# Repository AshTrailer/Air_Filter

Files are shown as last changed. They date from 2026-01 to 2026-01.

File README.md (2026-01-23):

## Air_Filter

Air_Filter is a compact, modular soldering fume extraction and air filtration device designed as a personal hardware project.

The enclosure measures approximately 9.8 × 11 × 11 cm and is constructed as a two-part, chamfered square housing, assembled using M3 fasteners. Inside, it integrates a Sanyo centrifugal blower capable of generating nearly 700 Pa of static pressure at 12 V, providing strong suction performance for soldering smoke removal.

Power is supplied via a standard DC jack, and airflow is adjustable through a rotary PWM control knob. The fan speed is controlled by a potentiometer-driven PWM generator, allowing smooth and flexible airflow regulation.

The mechanical design supports multiple fan orientations. In an upright configuration (front-facing intake), the device allows three different placement orientations. When laid horizontally, the outlet direction can be freely adjusted to suit different workspace layouts.

The filtration module is designed to be detachable and replaceable, enabling easy maintenance and future filter upgrades.

This repository documents the mechanical design, electronics, and overall system concept of the Air_Filter project, intended for learning, experimentation, and open-source sharing.

## Air_Filter
Air_Filter 是一个紧凑型、模块化的焊接烟气过滤与空气抽吸装置，是一个个人硬件设计与实现项目。

整机外壳尺寸约为 9.8 × 11 × 11 cm，采用带倒角的方形结构设计，由上下两部分组成，通过 M3 螺丝与螺母进行装配固定。内部集成了一款山洋（Sanyo）离心风机，在 12 V 供电条件下可提供接近 700 Pa 的静压，具备较强的烟气抽吸能力，适用于焊接烟雾的捕集与过滤。

设备通过标准 DC Jack 接口供电，侧面设有 PWM 调速旋钮。风机转速由电位器控制的 PWM 发生器进行调节，可实现平滑、可控的风量调节。

在结构设计上，该风机支持多种安装与摆放方式。在竖直放置（正面进气）的情况下，可实现三种不同的摆放方向；在水平放置时，出风口方向可根据使用环境自由调整，以适应不同的工作台布局。

过滤模块采用可拆卸、可更换的结构设计，便于维护与后续升级不同类型的过滤介质。

本仓库用于记录 Air_Filter 项目的整体设计思路，包括机械结构、电气控制以及系统集成方案，主要用于学习、实验与开源分享。

## Design Background & Motivation  
## 设计背景与动机

**时间：2026 年 1 月 12 日**

在日常焊接过程中，无论是 DIY 用户还是电子工程相关学习者，都会不可避免地接触到大量焊接烟气。这些烟气中往往包含松香、助焊剂残留以及细小颗粒物，长期吸入对健康存在潜在危害。

在调研过程中发现，市面上常见的焊接烟气过滤装置普遍存在以下问题：

- 体积较大，占用工作台空间  
- 价格偏高，不适合个人或 DIY 用户  
- 结构封闭，难以维护或自行改造  

因此，基于**小型化、可维护、可复用、适合个人工作台**的目标，萌生了自行设计并实现一款紧凑型焊接烟气过滤装置的想法。

在实际设计与制作过程中遇到了大量问题，包括结构强度、风道设计、噪声控制、过滤效率与体积之间的权衡等。这些问题均在实践中逐一分析并尝试解决。目前该项目已经基本完成既定目标。

---
Design Evolution & Versions
设计迭代与版本演进

This project is developed iteratively. Each version focuses on validating different aspects of mechanical design, airflow performance, noise control, and manufacturability.
The following sections document the design rationale, trade-offs, and lessons learned from each version.
Testing

---
Version 1 – Initial Prototype
第一版原型设计（V1）

Development Time: January 12, 2026
Status: Functional prototype


V2_3d_print
V1_total_view
V1_dimension_1
V1_dimension_2

Design Objectives
设计目标

The first version focused on validating the core feasibility of a compact, desktop-sized soldering fume extraction device, with the following priorities:
Compact overall size suitable for personal workbenches
Sufficient suction performance for soldering smoke capture
Modular structure for easy disassembly and maintenance
Rapid prototyping using 3D printing

第一版主要用于验证一款紧凑型桌面焊接烟雾抽取装置的核心可行性，设计优先考虑以下方面：
体积紧凑，适合个人工作台
吸烟能力足够捕集焊接烟雾
模块化结构，便于拆装和维护
通过 3D 打印快速原型制作

---
Overall Architecture
整体结构

The system is divided into two primary modules:
Base Module – fan mounting and structural support
Transmission Roll Module – airflow guidance and filtration
This modular approach simplifies assembly, maintenance, and future design iterations.

系统分为两个主要模块：
Base Module（风机基座） – 用于风机固定和结构支撑
Transmission Roll Module（过滤与风道模块） – 用于气流导向和过滤
这种模块化设计简化了装配、维护以及未来迭代。

---
Base Module Design
Base（风机基座）设计

The Base module is responsible for mounting and supporting the centrifugal blower.
Key design considerations include:
Strict adherence to fan datasheet dimensions and mounting features
Structural strength based on the mechanical properties of 3D printing materials
Support for multiple fan orientations and placement configurations
Special attention was paid to screw load distribution, wall thickness, and vibration caused by fan operation to ensure long-term mechanical reliability.

Base 模块用于固定和支撑离心风机。
主要设计考虑：
严格遵循风机 datasheet 中的安装尺寸和特征
基于 3D 打印材料力学特性确保结构强度
支持多种风机摆放方向和安装方式
特别注意了螺丝受力分布、壁厚设计，以及风机运行时产生的振动，保证长期机械可靠性。

---
Transmission Roll Module
Transmission Roll（过滤与风道模块）

This module handles airflow redirection, filtration, and exhaust.
Design goals:
Compact and portable form factor
Detachable and replaceable filtration module
Reduced internal dead zones and ineffective airflow paths
To minimize overall size, the V1 design abandoned a traditional long, straight duct and instead adopted a short, rapidly changing airflow path.

Trade-off:
This approach increased airflow turbulence, resulting in noticeably higher noise levels during operation.
Mitigation strategy:
Fan speed reduction via PWM control
Accepting reduced peak suction in exchange for improved acoustic comfort

该模块负责气流导向、过滤和排风。
设计目标：
小型便携
可拆卸、更换的过滤模块
减少内部死角和无效风道
为控制整体尺寸，V1 设计舍弃了传统长直风道，采用短而快速变化的风道。

权衡：
这种设计增加了气流湍流，导致运行时噪声明显增加。
解决策略：
通过 PWM 调速降低风机转速
在可接受吸力范围内，以牺牲峰值性能换取更舒适的噪声水平

---
Fan Selection & Filtration Strategy
风机选型与过滤方案

A Sanyo centrifugal blower was selected due to its ability to provide high static pressure (~700 Pa at 12 V), which is critical for overcoming the pressure drop introduced by multi-stage filtration.
The filtration strategy consists of:
Pre-filter (large particle interception)
HEPA filter (fine particle capture)
Activated carbon layer (odor and gas adsorption)
This combination targets typical soldering fumes containing rosin vapors, flux residues, and fine particulates.

选用 Sanyo 离心风机，因为其可以提供高静压（约 700 Pa @ 12 V），能够克服多级过滤带来的压力损失。
过滤方案包括：
初滤（拦截大颗粒）
HEPA 滤材（拦截细小颗粒）
活性炭层（吸附气味及部分有害气体）
组合设计针对典型焊接烟雾中的松香蒸气、助焊剂残留和细微颗粒物。

---
ilter Shape & Transition Geometry
过滤形状与过渡结构

A circular filter geometry was selected after comparing square and circular alternatives, due to:
Easier replacement and sealing
Symmetric structural loading
More uniform airflow distribution
Airflow transition design referenced equivalent half-angle theory:
Ideal half-angle: < 7° to minimize flow separation
V1 equivalent half-angle: > 50° due to size constraints
Although suboptimal from a fluid dynamics perspective, the circular transition maximizes usable area and reduces severe localized vortices under tight space limitations.

在比较方形和圆形方案后，最终选择圆形过滤结构，原因如下：
更易于更换和密封
结构对称，受力均匀
气流分布更均匀
气流过渡设计参考等效半角理论：
理想半角：小于 7°，可减少流动分离
V1 等效半角：大于 50°，受空间限制
虽然从流体动力学角度并非最优，但圆形结构在有限空间内最大化可用面积，并减少局部涡流。

---
Filter Thickness & Safety Considerations
过滤厚度与安全设计

To balance filtration performance and device thickness:
Filter module thickness was limited to ≤ 30 mm
A protective mesh was added at the exhaust outlet to prevent accidental contact with the fan impeller, improving user safety.

为平衡过滤效果和设备厚度：
过滤模块厚度限制为 ≤ 30 mm
在出风口增加防护网，防止误触风机叶轮，提高使用安全性。

---
Version 2 – Optimisation & Iteration
第二版优化设计（V2）
Development Time: January 13, 2026 – January 23, 2026
Status: Completed prototype, validated through testing
V2_total_view
V2_section_view
V2_3d_print

---
Identified Issues in Version 1
第一版（V1）问题总结

During assembly and testing of Version 1, several design limitations were identified:
Overly compact internal structure, leaving insufficient space for mounting control PCBs
The rear enclosure was secured with only two screws, resulting in noticeable gaps at the two unsupported corners
These mechanical issues were not fully considered during early-stage design due to limited prior experience
In practical testing, the airflow transition geometry exhibited a very large equivalent half-angle, leading to significant airflow-induced noise
These issues motivated a comprehensive redesign rather than incremental modification.

在 V1 装配和测试过程中，发现几个设计局限：
内部结构过于紧凑，无法合理安装控制电路板
后壳仅使用两颗螺丝固定，导致未支撑的两个角有明显缝隙
这些机械问题在早期设计阶段未充分考虑，主要由于经验不足
实测中，气流过渡几何结构等效半角过大，导致风噪明显
这些问题促使进行整体重新设计，而非简单改进。

---
Design Changes in Version 2
第二版（V2）设计改进

To address the limitations of V1, Version 2 introduces a scaled-up and structurally refined design.
Mechanical & Structural Improvements:
Overall enclosure dimensions increased to 120 × 120 × 120 mm (L × W × H)
Uniform corner fillets applied on all edges for improved structural consistency and aesthetics
Enclosure fabricated using grey PLA via 3D printing
Improved fastening strategy with symmetrical screw placement to eliminate corner gaps
Reserved internal space for PCB installation and cable routing

为解决 V1 问题，V2 对结构进行放大并优化设计。
机械与结构改进：
外壳尺寸增加至 120 × 120 × 120 mm（长 × 宽 × 高）
四周均匀圆角，提高结构一致性和美观
使用灰色 PLA 3D 打印制造
螺丝固定改为对称布置，消除角缝
为 PCB 安装和走线预留内部空间

Airflow & Acoustic Optimisation:
Airflow transition geometry redesigned
Equivalent half-angle reduced by approximately 20°, from over 50° in V1 to ~30° in V2
This change significantly reduced airflow turbulence and resulted in noticeably lower wind noise during operation

气流与噪声优化：
重新设计气流过渡结构
等效半角降低约 20°，从 V1 的 50°以上降至 约 30°
显著降低气流湍流，噪声明显下降

---
Cost Breakdown & Component Selection
成本与器件选型

The total cost of a single unit in Version 2 is controlled to remain below RMB 100, excluding development time.
Component	Description	Cost (RMB)
3D printed enclosure	PLA material	~13
Centrifugal blower	Sanyo 9BAM12P2J06	~50
4-pin PWM fan control	Fan PWM controller	~4.9
Custom filter elements	3 units	~30
Wiring & connectors	XH2.54 connectors
AWG18 / AWG26 wires	

成本与器件选型
V2 单机成本控制在 100 元人民币以内（不含开发时间）。
器件	              描述	              成本 (RMB)
3D 打印外壳	        PLA 材料	          ~13
离心风机	            Sanyo 9BAM12P2J06	  ~50
4-pin PWM 风机控制	  PWM 控制器	          ~4.9  
定制滤芯	3 个	                          ~33
若干线束与连接器	
XH2.54 接头
AWG18 / AWG26 线	

Testing Results & Further Optimisation
测试结果与后续优化空间

Practical testing of Version 2 showed that:
The redesigned airflow path significantly improved acoustic performance
The selected Sanyo centrifugal blower provides more suction capability than strictly required
Based on these observations, future iterations may adopt a lower-power centrifugal fan to further reduce overall cost, power consumption, and noise, while still meeting performance requirements.

V2 实测结果显示：
改进后的气流路径明显降低了噪声
所选 Sanyo 离心风机的吸力超出实际需求
未来迭代可能采用功率更低的离心风机，以进一步降低成本、功耗和噪声，同时仍能满足性能要求。

Summary
版本总结

Version 2 represents a substantial improvement over Version 1 by resolving key mechanical, acoustic, and integration issues.
This iteration demonstrates a clearer balance between performance, noise, manufacturability, cost, and practical usability, and provides a more robust foundation for future refinement.

V2 相比 V1，在机械、气流和集成方面有显著改进。
该版本在性能、噪声、可制造性、成本和实用性之间取得更好的平衡，为后续优化提供了稳固基础。

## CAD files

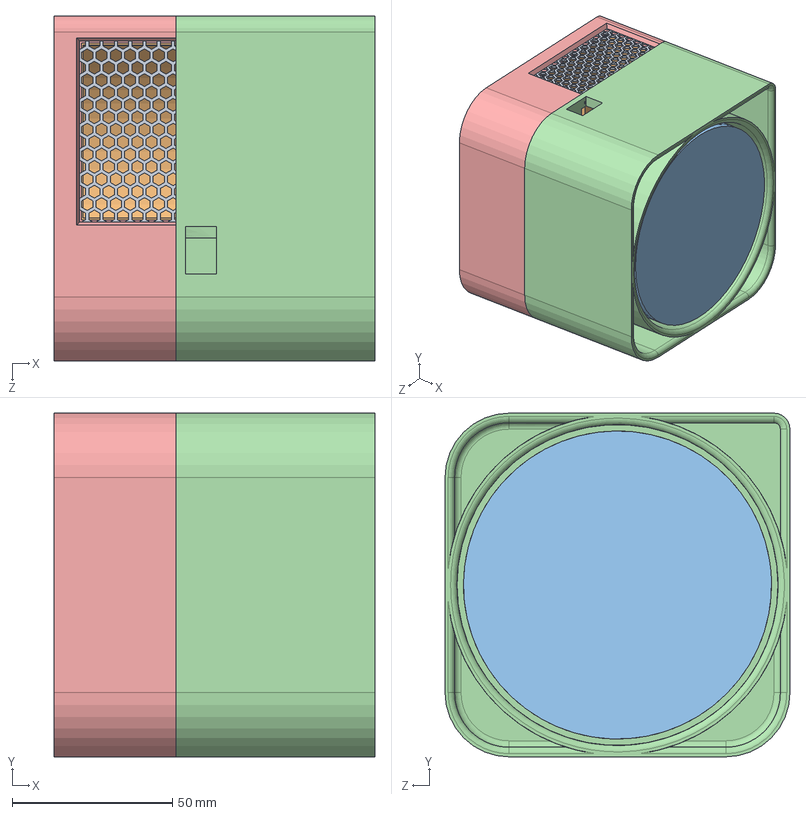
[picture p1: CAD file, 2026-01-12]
Assem.SLDASM
100.0 x 107.1 x 107.5 mm
Base_1
Trammission_Roll_2
Filter_Part
Fan_Part
Net3

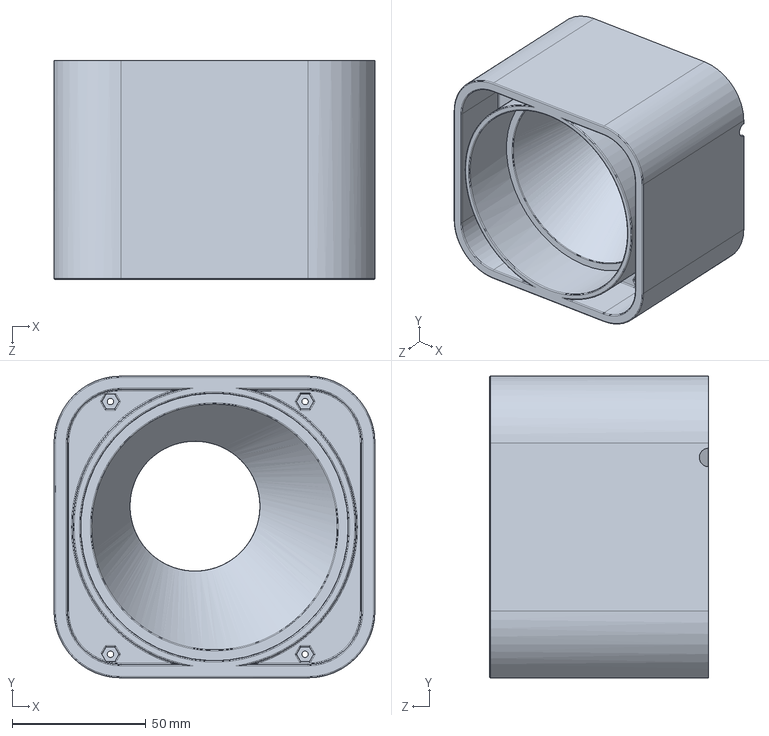
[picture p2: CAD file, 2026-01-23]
Filter_Part_2.SLDPRT
120.0 x 112.8 x 82.0 mm

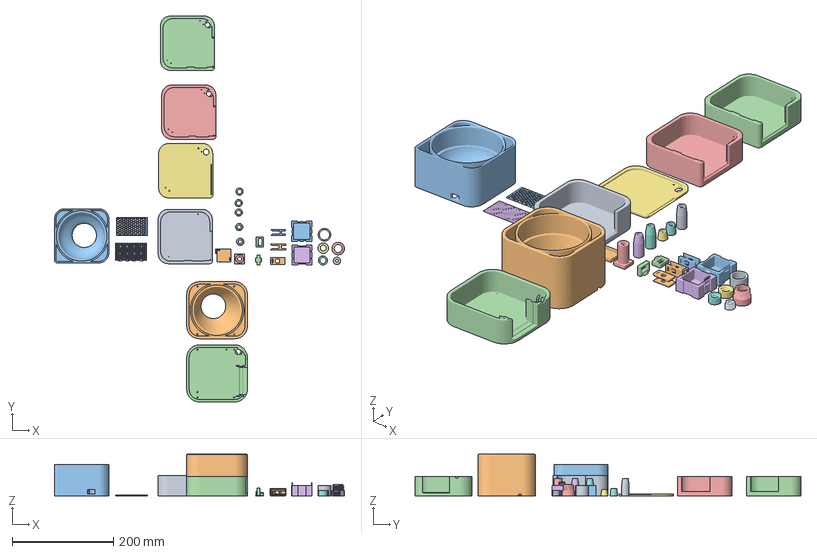
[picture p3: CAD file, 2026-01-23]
Test_Platform.3mf
573.0 x 762.4 x 82.0 mm
Test_screw_4.STL
Filter_Part_2.STL
Trammission_Roll_2.STL
Base_2.STL
Base_1.STL x 3
Net2.STL
Base_1.STL_B_A
Test_Connector_1.STL x 4
Test_block_3.STL
Test_block_1.STL
Test_block_4.STL x 2
Test_screw_5.STL
Test_Block_2.STL
Test_screw_2.STL
Test_screw_3.STL
Test_screw_1.STL
Test_block_3-增厚连接处并增加墙层数-50填充.STL
Test_block_3-增加墙层数-50填充.STL
Test_Connector_1.STL_A x 2
PWM_Control_Test.STL
Net3.STL

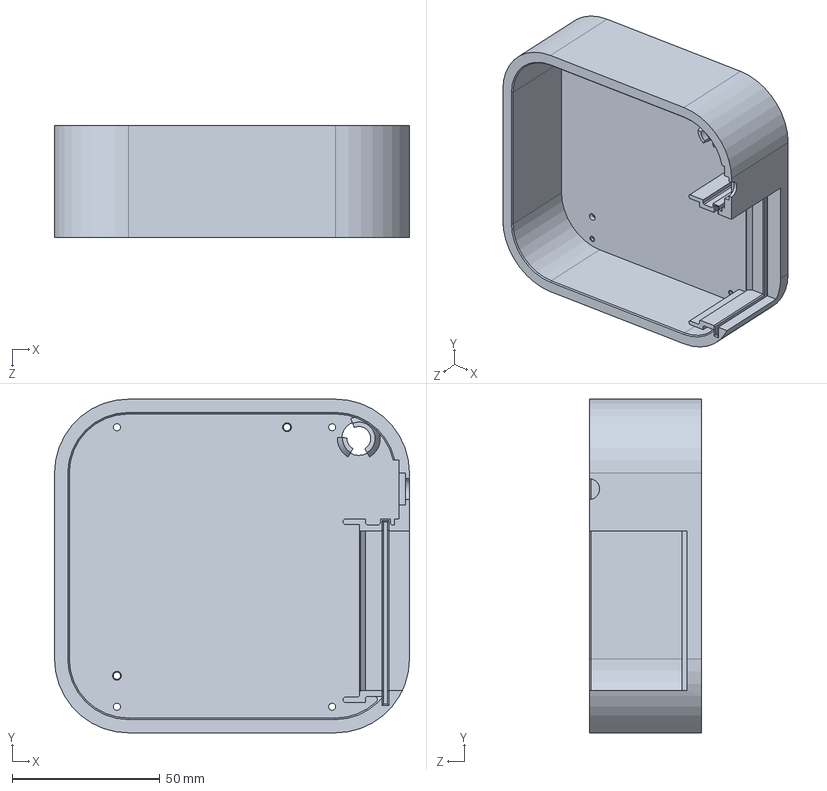
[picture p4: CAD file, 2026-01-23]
Base_2.SLDPRT
120.0 x 112.8 x 38.0 mm

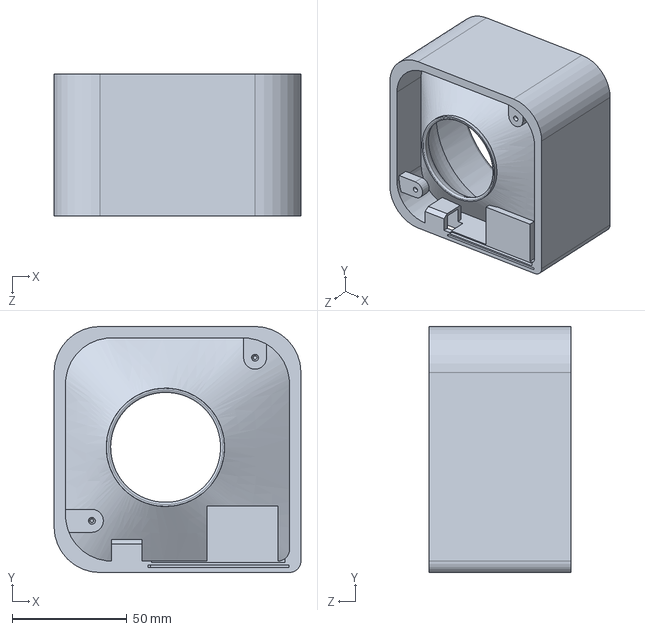
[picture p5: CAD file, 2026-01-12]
Trammission_Roll_2.SLDPRT
107.5 x 107.1 x 62.0 mm

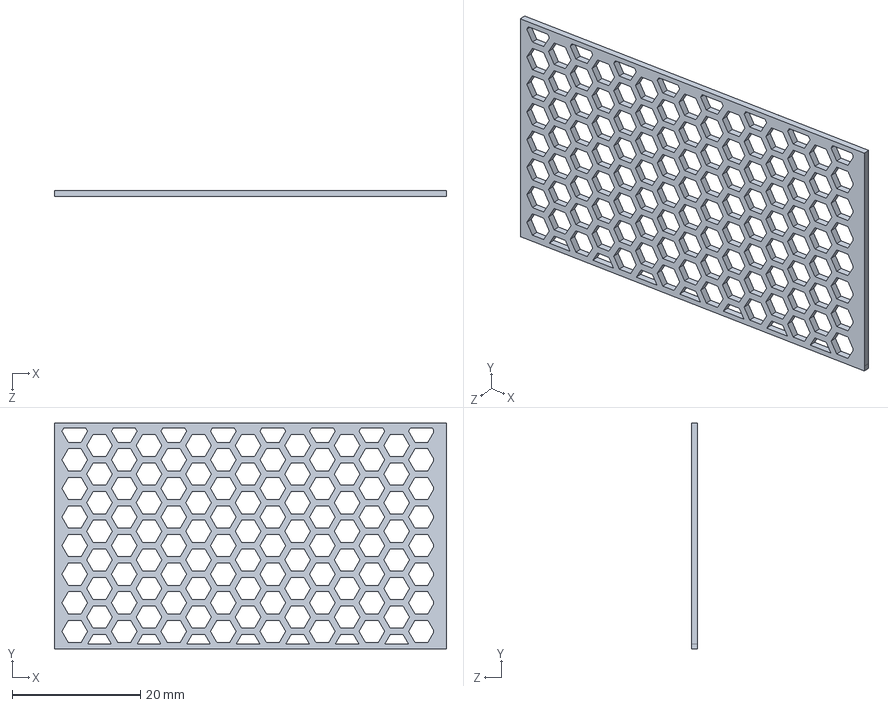
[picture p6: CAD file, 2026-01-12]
Net3.SLDPRT
61.1 x 35.2 x 1 mm

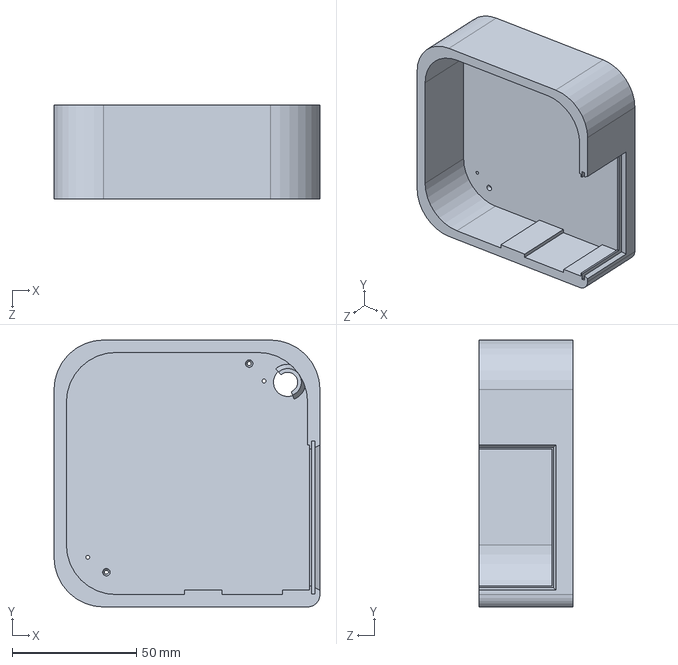
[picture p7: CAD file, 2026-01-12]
Base_1.SLDPRT
107.1 x 107.5 x 38.0 mm

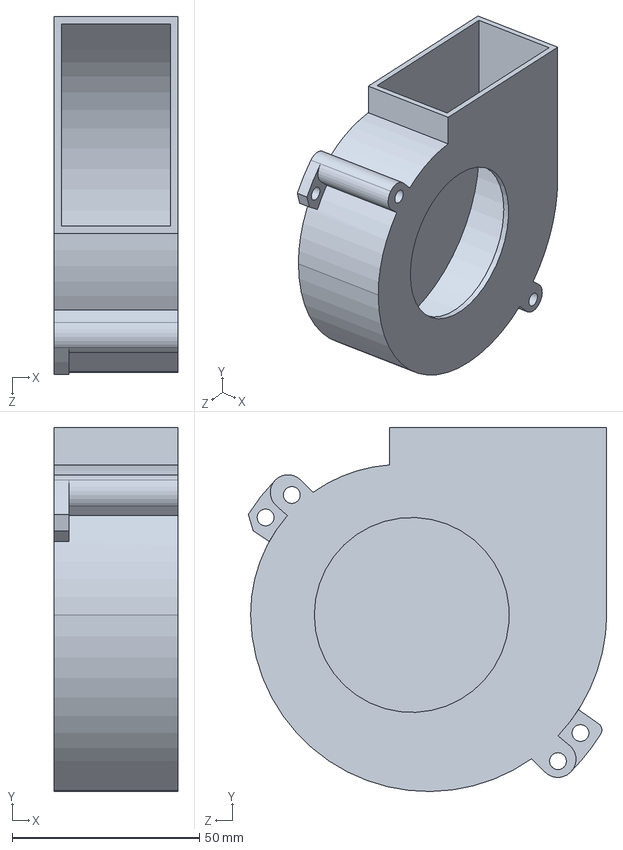
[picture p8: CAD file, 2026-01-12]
Fan_Part.SLDPRT
33.0 x 97.1 x 95.6 mm

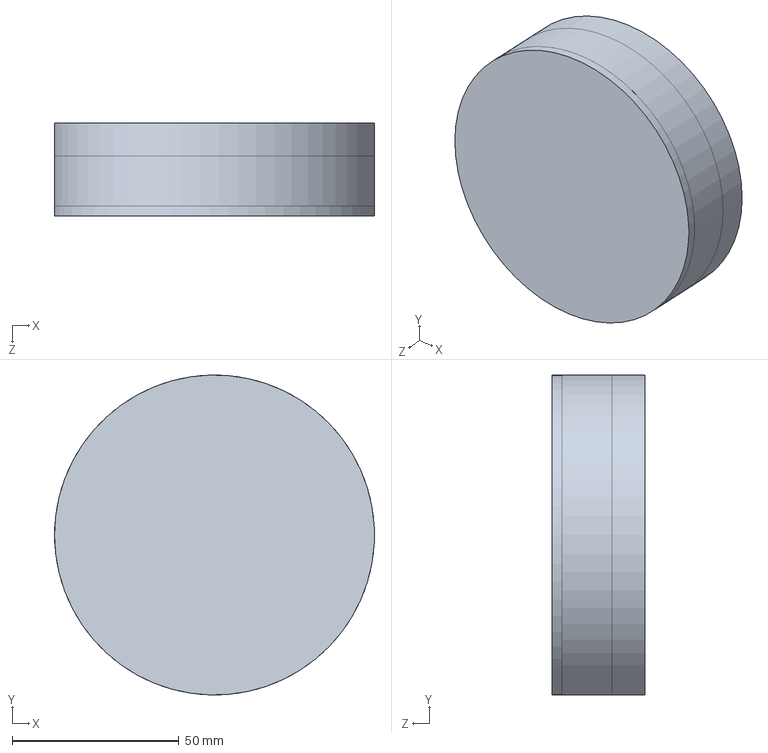
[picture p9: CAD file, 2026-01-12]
Filter_Part.SLDPRT
96.0 x 96.0 x 28.0 mm

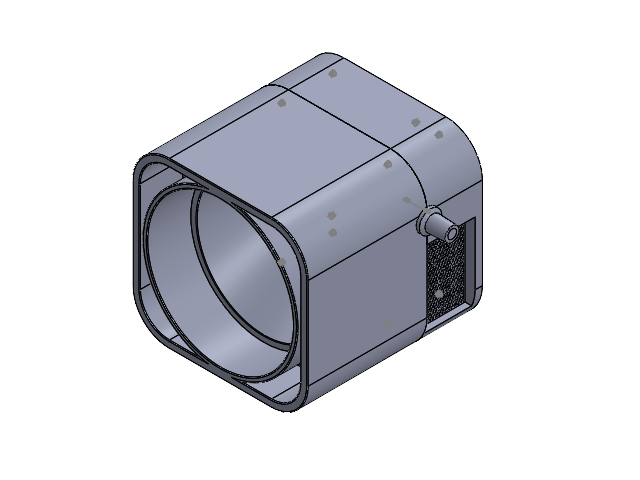
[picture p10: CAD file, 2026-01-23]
Assem2.SLDASM
Base_2
Fan_Part
PCB_Plcaement
Power_input_placement
Filter_Part_2
Knob
Net2

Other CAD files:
Base_1.STL
Base_2.STL
Filter_Part_2.STL
Net3.STL
Trammission_Roll_2.STL

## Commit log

2026-01-12 Add files via upload
    Upload related files
    [Assem.SLDASM, Base_1.SLDPRT, Base_1.STL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]
2026-01-12 Enhance README with project details and design insights
    Expanded the README to include project background, design considerations, and current status.
